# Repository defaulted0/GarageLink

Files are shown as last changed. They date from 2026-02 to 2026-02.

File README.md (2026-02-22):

# GarageLink
**A local, DIY smart garage controller built on the Raspberry Pi Pico 2 W.**

> [!IMPORTANT]
> GarageLink needs an existing HomeAssistant setup to function. You may need additional devices beyond those outlined in the ReadMe.

## Overview

GarageLink is a Home Assistant–integrated garage controller that simulates a wall button press using a relay.  
It connects over WiFi, publishes via MQTT, and adds movement-aware status correction (optional).

It works by momentarily bridging the same two terminals used by the wall button, effectively simulating a button press.

---

## Hardware Requirements

### 1. Raspberry Pi Pico 2 W
- Built-in WiFi
- Controls relays and sensors
- Connects everything

### 2. 5V Relay Module
- Used to simulate a wall button press
- COM and NO terminals only
- Optocoupled boards preferred

### 3. Low-Voltage Wire / Thermostat / Doorbell Wire (18/2 or 22/2 solid copper)
- Pretty cheap on Amazon
- Doorbell, Thermostat, and low-voltage wire are all basically the same.
- Used to connect the relay to the opener terminals
- **Highly** recommended to mount your GarageLink away from the main opener as the WiFi on GarageLink interferes with the RF signal your garage remote uses and your car uses.

### 4. Optional Sensors
- SW-420 vibration sensor
- Used to update the open/close status if an outside entity controls the door. (Wall button, HomeLink, etc.)
- Mark Open and Mark Closed triggers are published to HomeAssistant, too.

## 5. 5V Power Supply
- USB wall adapter works perfectly
- Check if you have a wall outlet near your garage; you probably do. If not, try not to use a battery pack as the voltage is unreliable, and who wants to charge their garage door?

---

## Wiring / Hardware Setup

> [!CAUTION]
> Disconnect the power to your opener before installation.

### Pico → Relay

| Pico Pin | Relay Pin |
|---|---|
| GP17 | IN2 |
| GP16 | IN1 |
| GND | GND |
| VSYS | VCC (5V)  |

>The "IN" pin corresponds to the relay you use on your board.
Adjust GPIO pins as needed in the code.
Use both IN1 and IN2 when wiring two garage doors. If not, use one.
---

### Relay → Garage Opener

For each door:

| Relay Terminal | Opener Terminal |
|---|---|
| COM | Wall terminal |
| NO | Wall terminal |

- Leave NC unused.
- Keep existing wall button wires connected.
- It doesn't matter which order, but which terminals do. Check where your garage's wall buttons connect.
> [!IMPORTANT]
> Check if your wall buttons still work; stuff happens. Better to be safe.

---

### Optional Vibration Sensor

| Sensor Pin | Pico Pin |
|---|---|
| VCC | 3V3 |
| GND | GND |
| DO | GP14 |

Used only for movement detection, not for triggering the relay.

---

## Software Setup

### 1. Install Thonny
https://thonny.org

### 2. Flash MicroPython on Pico
- In the bottom right corner, click the Interpreter, then Configure interpreter.
- At the top, select the Interpreter "MicroPython (RP2040)"
- Click "Install or update MicroPython"
- Choose your Pico as the Target Volume
- MicroPython Family: RP2
- Variant: Raspberry Pi Pico 2 W
- Install

### 3. Upload Files
- Paste in `garage.py`
- Save it to the Pico as `garage.py`
  
- Paste in `main.py`
- Save it to the Pico as `main.py`
> GarageLink will now auto-run on boot.

## Home Assistant Setup

GarageLink uses MQTT discovery.

>[!IMPORTANT]
>Make a new user in HomeAssistant for MQTT. You will use its details for the MQTT config.

Requirements:
- MQTT broker running
- Home Assistant installed
- MQTT integration enabled

Once connected, the following entities should appear:
- `cover.garage_door`
- Availability sensor (if applicable)
- Sync buttons

---

## Configuration

The table is what setting, and then which variable that setting is.

| Setting | Variable |
|---|---|
| WiFi Name | WIFI_SSID = “” |
| Wifi Password | WIFI_PASS = “” | 
| MQTT Host (Usually HomeAssistant IP) | MQTT_BROKER="" |
| MQTT Username | MQTT_USER="" |
| MQTT Password | MQTT_PASS=""

>[!NOTE]
>Make sure all of the necessary fields have been edited in `garage.py`

---
## Status LED

- GarageLink includes support for a recommended status LED.
- Connects to GP12 and GND

- Error Codes and meanings are available in the docs section of this repo.

## Install Install

### 1. Find install area
Decide and find the installation area near your garage opener. **Please** don't just put it on top of the door opener. You'll regret it down the line. Ideal to put it on your ceiling, 2-4 feet away. Further = Better (Kinda)

### 2. Install GarageLink Box
Drill or screw or tape or whatever your GarageLink box into your installation area. If you are too cool to print the one I made, make your own. I don't care. Make sure your wire fits before fully installing it.

### 3. Prepare and strip wires.
Strip your low-voltage wire to length and expose both ends on each side. Connect an optional LED to GPIO 12.

### 4. Connect it up
Connect everything up with the outlined wiring instructions above.

### 5. Done!
Plug in GarageLink and yay! If it doesn't work, check logs, and *please* feel free to create an issue on GitHub.

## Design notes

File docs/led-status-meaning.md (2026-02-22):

# LED Status Reference

GarageLink includes a single status LED to communicate system state without requiring Home Assistant access.

This LED provides live feedback about:

- WiFi connection
- MQTT connection
- Door position state
- Door movement
- Error or unknown states

This document explains exactly what each LED pattern means.

---

## Quick Reference

| LED Pattern | Meaning |
|---|---|
| Solid ON | System healthy, door CLOSED |
| Mostly ON, brief OFF pulse | System healthy, door OPEN |
| Slow blink (0.5s on / 0.5s off) | Door is moving |
| Double blink, pause | Unknown or stopped state |
| OFF | Not connected to MQTT |
| Short flash every ~2s | Reconnecting to MQTT |

---

## Detailed Behavior

### Solid ON

The LED remains continuously ON.

Indicates:
- WiFi connected
- MQTT connected
- System healthy
- Door state is known
- Door is CLOSED

This is the normal idle state.

---

### Mostly ON With Brief OFF Pulse

The LED stays ON but briefly turns OFF every few seconds.

Indicates:
- WiFi connected
- MQTT connected
- Door is OPEN

This subtle pulse acts as a reminder that the garage door is not closed.

---

### Slow Blink (500ms On / 500ms Off)

The LED blinks evenly at a steady rhythm.

Indicates:
- Door is OPENING
- Door is CLOSING

This state occurs:
- After a command is sent
- When movement is detected

---

### Double Blink Pattern

Two quick flashes followed by a pause.

Indicates:
- Door state is UNKNOWN
- Door state is STOPPED
- System recently rebooted
- State synchronization incomplete

This usually resolves once the door state is confirmed.

---

### LED OFF

The LED remains completely OFF.

Indicates:
- Not connected to MQTT
- Broker unreachable
- Network failure
- Device booting but not yet connected

If the LED remains OFF for more than 30 seconds after boot, check:

- WiFi credentials
- MQTT broker IP
- Power supply

---

### Short Flash Every ~2 Seconds

Single short flash at regular intervals.

Indicates:
- Attempting to reconnect to MQTT
- Temporary network interruption

The LED will return to normal state once MQTT reconnects.

---

### Startup Indicators

On boot, the LED provides quick visual confirmation:

- 2 quick flashes → WiFi connected
- 3 quick flashes → MQTT connected

After startup completes, the LED switches to standard operating patterns.

---

### Hardware Wiring

Standard wiring configuration:

- GPIO 12 → 330Ω resistor → LED anode (long leg)
- LED cathode (short leg) → GND

The resistor may be placed on either side of the LED.

---

### Notes

- LED patterns are designed for low visual noise.
- Only one LED is used.
- No RGB or multi-color signaling is implemented.
- System health is primarily reflected by MQTT connectivity.

**Start a discussion or fork if you want to change anything or have any better ideas!**

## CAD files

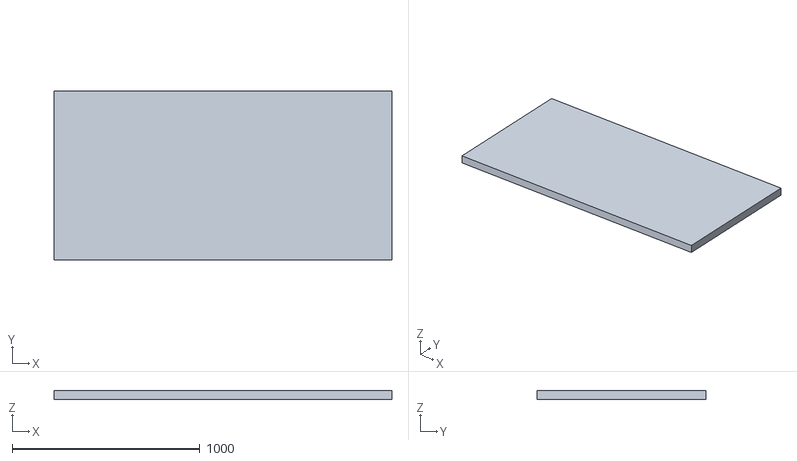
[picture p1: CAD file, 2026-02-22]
case/lid.stl
1800.0 x 900.0 x 50.0

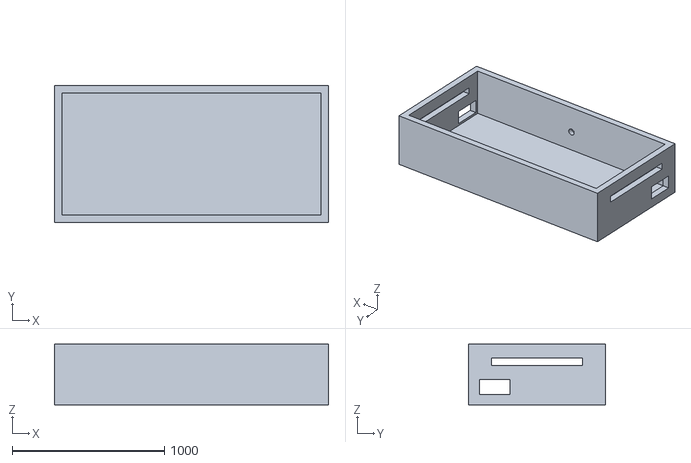
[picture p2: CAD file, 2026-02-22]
case/shell.stl
1800.0 x 900.0 x 400.0

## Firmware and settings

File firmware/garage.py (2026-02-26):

# GarageLink by default
# ------------------------------------------------
print("[BOOT] Pico garage script starting")

import time
import machine    # type: ignore
import network    # type: ignore
import ubinascii  # type: ignore
import ujson      # type: ignore

# MQTT library (make sure /lib/umqtt/simple.py exists on the Pico)
from umqtt.simple import MQTTClient  # type: ignore


# ================================================================                        EDIT HERE!!!!
# USER SETTINGS  (EDIT THESE)                                                         <-------------
# ================================================================
WIFI_SSID = "YOUR_WIFI_NAME"
WIFI_PASS = "YOUR_WIFI_PASSWORD"

MQTT_BROKER = ""     # <--- usually just the ip of your homeassistant host
MQTT_PORT   = 1883
MQTT_USER   = ""
MQTT_PASS   = ""

BASE_TOPIC  = "pico2w/garage1"

# Relay output (your relay IN2 is on GP17)
RELAY_PIN = 17
RELAY_ACTIVE_LOW = True

# Pulse duration (button press length)
PULSE_MS   = 500
LOCKOUT_MS = 3000

# Estimated travel time (used for opening/closing status)
TRAVEL_MS = 14000
IGNORE_WHILE_MOVING = True

# Status LED
LED_PIN = 12
LED_ACTIVE_HIGH = True

# Door position sensor (reed) - OFF by default
USE_DOOR_SENSOR = False
DOOR_PIN = 14
DOOR_OPEN_WHEN_PIN_LOW = True

# Vibration sensor (SW-420) - OFF by default
USE_VIBRATION = False
VIB_PIN = 14
VIB_ACTIVE_HIGH = True
VIB_MIN_MS = 2000                 # must vibrate this long to count as motion
VIB_IGNORE_AFTER_CMD_MS = 3000    # ignore vibration right after relay press
VIB_NO_MOVE_ALERT_MS = 6000       # publish alert if no vibration after command
VIB_END_QUIET_MS = 1500           # how long of quiet to consider motion ended
# ================================================================


# ----------------------------
# Topics
# ----------------------------
CMD_TOPIC    = BASE_TOPIC + "/command"       # HA -> Pico
SYNC_TOPIC   = BASE_TOPIC + "/sync"          # HA -> Pico (mark open/closed)
STATUS_TOPIC = BASE_TOPIC + "/status"        # Pico -> HA (cover state)
STATE_TOPIC  = BASE_TOPIC + "/door_state"    # Pico -> HA (binary sensor if reed enabled)
AVAIL_TOPIC  = BASE_TOPIC + "/availability"  # online/offline
ALERT_TOPIC  = BASE_TOPIC + "/alert"         

DISCOVERY_PREFIX = "homeassistant"


# LED helpers
wifi_ok = False
mqtt_ok = False
led_state = "UNKNOWN"
led_trying = False
_led_last_ms = 0
_led_phase = 0
_led_on = False

def led_init():
    try:
        return machine.Pin(LED_PIN, machine.Pin.OUT)
    except Exception:
        try:
            return machine.Pin(25, machine.Pin.OUT)
        except Exception:
            return None

def led_set(led, on: bool):
    if led is None:
        return
    val = 1 if on else 0
    if not LED_ACTIVE_HIGH:
        val ^= 1
    led.value(val)

def led_blink(led, count=1, on_ms=120, off_ms=120):
    if led is None:
        return
    for _ in range(count):
        led_set(led, True)
        time.sleep_ms(on_ms)
        led_set(led, False)
        time.sleep_ms(off_ms)

def led_tick(led, est_state_now: str):
    global _led_last_ms, _led_phase, _led_on

    if led is None:
        return

    s = (est_state_now or "UNKNOWN").upper()
    now = time.ticks_ms()

    if not mqtt_ok:
        if not led_trying:
            led_set(led, False)
            _led_on = False
            _led_phase = 0
            _led_last_ms = now
            return

        # trying
        if _led_phase == 0:
            led_set(led, True)
            _led_on = True
            _led_phase = 1
            _led_last_ms = now
        else:
            if _led_on and time.ticks_diff(now, _led_last_ms) >= 120:
                led_set(led, False)
                _led_on = False
            if time.ticks_diff(now, _led_last_ms) >= 2000:
                _led_phase = 0
                _led_last_ms = now
        return

    if s == "CLOSED":
        led_set(led, True)
        _led_on = True
        _led_phase = 0
        _led_last_ms = now
        return

    if s == "OPEN":
        if time.ticks_diff(now, _led_last_ms) >= 3000:
            _led_last_ms = now
            _led_phase = 0
        if _led_phase == 0:
            led_set(led, False)
            _led_on = False
            _led_phase = 1
            _led_last_ms = now
        elif _led_phase == 1 and time.ticks_diff(now, _led_last_ms) >= 120:
            led_set(led, True)
            _led_on = True
            _led_phase = 2
        return

    if s in ("OPENING", "CLOSING"):
        if time.ticks_diff(now, _led_last_ms) >= 500:
            _led_last_ms = now
            _led_on = not _led_on
            led_set(led, _led_on)
        return

    # unknown/stopped
    if _led_phase == 0:
        led_set(led, True)
        _led_on = True
        _led_phase = 1
        _led_last_ms = now
    elif _led_phase == 1 and time.ticks_diff(now, _led_last_ms) >= 120:
        led_set(led, False)
        _led_on = False
        _led_phase = 2
        _led_last_ms = now
    elif _led_phase == 2 and time.ticks_diff(now, _led_last_ms) >= 120:
        led_set(led, True)
        _led_on = True
        _led_phase = 3
        _led_last_ms = now
    elif _led_phase == 3 and time.ticks_diff(now, _led_last_ms) >= 120:
        led_set(led, False)
        _led_on = False
        _led_phase = 4
        _led_last_ms = now
    elif _led_phase == 4 and time.ticks_diff(now, _led_last_ms) >= 2640:
        _led_phase = 0
        _led_last_ms = now


# wifi/mqtt
def wifi_connect(led=None):
    global wifi_ok
    wlan = network.WLAN(network.STA_IF)
    wlan.active(True)
    print("[WIFI] Connecting to:", WIFI_SSID)

    try:
        hostname = "garagelink-" + ubinascii.hexlify(machine.unique_id())[-4:].decode()
        wlan.config(dhcp_hostname=hostname)
    except Exception:
        pass

    if wlan.isconnected():
        ip = wlan.ifconfig()[0]
        print("[WIFI] Already connected, IP:", ip)
        wifi_ok = True
        return wlan

    wlan.connect(WIFI_SSID, WIFI_PASS)
    t0 = time.ticks_ms()
    while not wlan.isconnected():
        if time.ticks_diff(time.ticks_ms(), t0) > 20000:
            raise RuntimeError("WiFi connect timeout")
        time.sleep_ms(250)

    ip = wlan.ifconfig()[0]
    print("[WIFI] Connected, IP:", ip)
    wifi_ok = True
    led_blink(led, count=2)
    return wlan

def mqtt_connect(client_id, will_topic, will_msg, led=None):
    global mqtt_ok
    print("[MQTT] Connecting to broker:", MQTT_BROKER)

    cid = client_id if isinstance(client_id, (bytes, bytearray)) else str(client_id).encode()
    usr = MQTT_USER.encode() if MQTT_USER else None
    pwd = MQTT_PASS.encode() if MQTT_PASS else None

    c = MQTTClient(
        client_id=cid,
        server=MQTT_BROKER,
        port=int(MQTT_PORT),
        user=usr,
        password=pwd,
        keepalive=60
    )
    c.set_last_will(will_topic, will_msg, retain=True, qos=0)
    c.connect()

    mqtt_ok = True
    print("[MQTT] Connected")
    led_blink(led, count=3)
    return c


# Home Assistant Discovery (MQTT)
def publish_discovery(client, unique, device_name):
    # Cover entity
    cover_id = unique + "_cover"
    cover_cfg_topic = f"{DISCOVERY_PREFIX}/cover/{cover_id}/config"
    cover_cfg = {
        "name": "GarageLink",   # just rename in homeassistant
        "unique_id": cover_id,
        "command_topic": CMD_TOPIC,
        "state_topic": STATUS_TOPIC,
        "availability_topic": AVAIL_TOPIC,
        "payload_available": "online",
        "payload_not_available": "offline",
        "payload_open": "OPEN",
        "payload_close": "CLOSE",
        "payload_stop": "STOP",
        "state_open": "OPEN",
        "state_opening": "OPENING",
        "state_closed": "CLOSED",
        "state_closing": "CLOSING",
        "state_stopped": "STOPPED",
        "device": {
            "identifiers": [unique],
            "name": device_name,
            "manufacturer": "Raspberry Pi",
            "model": "Pico 2 W",
        }
    }
    client.publish(cover_cfg_topic, ujson.dumps(cover_cfg), retain=True)
    print("[MQTT] Discovery cover published")

    # Door binary sensor (reed)
    if USE_DOOR_SENSOR:
        sensor_id = unique + "_door"
        sensor_cfg_topic = f"{DISCOVERY_PREFIX}/binary_sensor/{sensor_id}/config"
        sensor_cfg = {
            "name": "Garage Door Open",
            "unique_id": sensor_id,
            "state_topic": STATE_TOPIC,
            "payload_on": "OPEN",
            "payload_off": "CLOSED",
            "device_class": "garage_door",
            "availability_topic": AVAIL_TOPIC,
            "payload_available": "online",
            "payload_not_available": "offline",
            "device": {
                "identifiers": [unique],
                "name": device_name,
                "manufacturer": "Raspberry Pi",
                "model": "Pico 2 W",
            }
        }
        client.publish(sensor_cfg_topic, ujson.dumps(sensor_cfg), retain=True)
        print("[MQTT] Discovery door sensor published")

    # Sync buttons
    sync_open_id = unique + "_sync_open"
    sync_open_cfg_topic = f"{DISCOVERY_PREFIX}/button/{sync_open_id}/config"
    sync_open_cfg = {
        "name": "Garage: Mark Open",
        "unique_id": sync_open_id,
        "command_topic": SYNC_TOPIC,
        "payload_press": "OPEN",
        "availability_topic": AVAIL_TOPIC,
        "payload_available": "online",
        "payload_not_available": "offline",
        "icon": "mdi:garage-open",
        "device": {
            "identifiers": [unique],
            "name": device_name,
            "manufacturer": "Raspberry Pi",
            "model": "Pico 2 W",
        }
    }
    client.publish(sync_open_cfg_topic, ujson.dumps(sync_open_cfg), retain=True)

    sync_closed_id = unique + "_sync_closed"
    sync_closed_cfg_topic = f"{DISCOVERY_PREFIX}/button/{sync_closed_id}/config"
    sync_closed_cfg = {
        "name": "Garage: Mark Closed",
        "unique_id": sync_closed_id,
        "command_topic": SYNC_TOPIC,
        "payload_press": "CLOSED",
        "availability_topic": AVAIL_TOPIC,
        "payload_available": "online",
        "payload_not_available": "offline",
        "icon": "mdi:garage",
        "device": {
            "identifiers": [unique],
            "name": device_name,
            "manufacturer": "Raspberry Pi",
            "model": "Pico 2 W",
        }
    }
    client.publish(sync_closed_cfg_topic, ujson.dumps(sync_closed_cfg), retain=True)
    print("[MQTT] Discovery sync buttons published")
# Relay control
def make_relay(pin_num):
    pin = machine.Pin(pin_num, machine.Pin.IN)  # Hi-Z idle
    print("[RELAY] Idle set to Hi-Z (Pin.IN) on GP", pin_num)
    return pin

def relay_pulse(relay_pin, led=None):
    print("[RELAY] Pulse triggered")
    # optional quick blink to show activity
    led_blink(led, count=2, on_ms=120, off_ms=120)

    if RELAY_ACTIVE_LOW:
        relay_pin.init(machine.Pin.OUT)
        relay_pin.value(0)
        time.sleep_ms(PULSE_MS)
        relay_pin.init(machine.Pin.IN)
    else:
        relay_pin.init(machine.Pin.OUT)
        relay_pin.value(1)
        time.sleep_ms(PULSE_MS)
        relay_pin.init(machine.Pin.IN)

    print("[RELAY] Returned to Hi-Z (Pin.IN)")

# Door sensor (reed) helper
def read_door_state(door_pin):
    v = door_pin.value()
    is_open = (v == 0) if DOOR_OPEN_WHEN_PIN_LOW else (v == 1)
    return "OPEN" if is_open else "CLOSED"

# Vibration helper
def vib_active(vpin):
    v = vpin.value()
    return (v == 1) if VIB_ACTIVE_HIGH else (v == 0)


# ----------------------------
# Main
# ----------------------------
unique = ubinascii.hexlify(machine.unique_id()).decode()
device_name = "GarageLink Controller"

led = led_init()
led_set(led, False)
print("[LED] Status LED init:", bool(led))

relay = make_relay(RELAY_PIN)
print("[RELAY] Initialized on GP", RELAY_PIN, "active_low =", RELAY_ACTIVE_LOW)

door_pin = None
last_door = None
if USE_DOOR_SENSOR:
    door_pin = machine.Pin(DOOR_PIN, machine.Pin.IN, machine.Pin.PULL_UP)
    last_door = read_door_state(door_pin)
    print("[DOOR] Initial:", last_door)

vpin = None
if USE_VIBRATION:
    vpin = machine.Pin(VIB_PIN, machine.Pin.IN)
    print("[VIB] Enabled on GP", VIB_PIN)

# State machine
est_state = "UNKNOWN"  # UNKNOWN/OPENING/CLOSING/OPEN/CLOSED/STOPPED Must open or close first to set state on boot!
move_end_ms = None
last_press_ms = 0

# Vibration logic state
_cmd_ms = None
_expect_motion = False
_vib_start_ms = None
_last_vib_ms = None
_motion_confirmed = False


def publish_status(client, state, retain=True):
    global est_state
    est_state = state
    try:
        client.publish(STATUS_TOPIC, state, retain=retain)
        print("[STATUS] ->", state)
    except Exception as e:
        print("[STATUS] publish failed:", e)

def publish_alert(client, text):
    try:
        client.publish(ALERT_TOPIC, text, retain=False)
        print("[ALERT] ->", text)
    except Exception as e:
        print("[ALERT] publish failed:", e)


def on_mqtt_msg(topic, msg):
    global last_press_ms, est_state, move_end_ms
    global _cmd_ms, _expect_motion, _motion_confirmed

    t = topic.decode() if isinstance(topic, (bytes, bytearray)) else str(topic)
    m = msg.decode().strip().upper()
    now = time.ticks_ms()
    print("[MQTT] RX:", t, m)

    # Sync buttons: correct state without moving
    if t == SYNC_TOPIC:
        if m in ("OPEN", "CLOSED", "UNKNOWN", "STOPPED"):
            move_end_ms = None
            publish_status(client, m, retain=True)
        return

    if t != CMD_TOPIC:
        return

    if m not in ("OPEN", "CLOSE", "STOP", "TRIGGER", "TOGGLE", "PRESS", "ON", "1"):
        return

    # Lockout
    if time.ticks_diff(now, last_press_ms) < LOCKOUT_MS:
        print("[RELAY] Ignored (lockout)")
        return

    # STOP: only meaningful while moving
    if m == "STOP":
        if est_state in ("OPENING", "CLOSING"):
            last_press_ms = now
            relay_pulse(relay, led=led)
            publish_status(client, "STOPPED", retain=True)
        return

    # Ignore while moving (optional)
    if IGNORE_WHILE_MOVING and est_state in ("OPENING", "CLOSING"):
        print("[STATE] Ignored (already moving):", est_state)
        return

    # Trigger relay
    last_press_ms = now
    relay_pulse(relay, led=led)

    # Mark that we "expect" motion soon (for vibration alert logic)
    _cmd_ms = now
    _expect_motion = True
    _motion_confirmed = False

    # Update estimated movement state
    if m == "OPEN":
        publish_status(client, "OPENING", retain=True)
    elif m == "CLOSE":
        publish_status(client, "CLOSING", retain=True)
    else:
        # toggle
        if est_state in ("CLOSED", "CLOSING", "UNKNOWN", "STOPPED"):
            publish_status(client, "OPENING", retain=True)
        else:
            publish_status(client, "CLOSING", retain=True)

    move_end_ms = time.ticks_add(now, TRAVEL_MS)


def safe_sleep_ms(ms):
    step = 50
    remaining = ms
    while remaining > 0:
        time.sleep_ms(step if remaining > step else remaining)
        remaining -= step


# Connect WiFi + MQTT
wifi_connect(led)

client_id = b"garagelink-" + ubinascii.hexlify(machine.unique_id())
client = mqtt_connect(client_id, AVAIL_TOPIC, b"offline", led=led)

client.set_callback(on_mqtt_msg)

client.subscribe(CMD_TOPIC.encode())
client.subscribe(SYNC_TOPIC.encode())
print("[MQTT] Subscribed:", CMD_TOPIC, "and", SYNC_TOPIC)

client.publish(AVAIL_TOPIC, b"online", retain=True)
print("[MQTT] Availability online")

publish_discovery(client, unique, device_name)

# Publish initial states
if USE_DOOR_SENSOR and last_door is not None:
    client.publish(STATE_TOPIC, last_door, retain=True)
    publish_status(client, last_door, retain=True)
else:
    publish_status(client, est_state, retain=True)


# Main loop
while True:
    try:
        client.check_msg()

        # LED tick
        led_tick(led, est_state)

        now = time.ticks_ms()

        # If no door sensor, timer completes OPENING/CLOSING into OPEN/CLOSED
        if (not USE_DOOR_SENSOR) and move_end_ms is not None and time.ticks_diff(now, move_end_ms) >= 0:
            if est_state == "OPENING":
                publish_status(client, "OPEN", retain=True)
            elif est_state == "CLOSING":
                publish_status(client, "CLOSED", retain=True)
            move_end_ms = None

        # Door sensor overrides estimate (true open/closed)
        if USE_DOOR_SENSOR and door_pin is not None:
            current = read_door_state(door_pin)
            if current != last_door:
                last_door = current
                print("[DOOR] Changed:", current)
                client.publish(STATE_TOPIC, current, retain=True)
                move_end_ms = None
                publish_status(client, current, retain=True)

        # Vibration-based movement detection (state correction only)
        if USE_VIBRATION and vpin is not None:
            active = vib_active(vpin)

            if active:
                if _vib_start_ms is None:
                    _vib_start_ms = now
                _last_vib_ms = now

                # Confirm sustained motion
                if time.ticks_diff(now, _vib_start_ms) >= VIB_MIN_MS:
                    _motion_confirmed = True
            else:
                _vib_start_ms = None

            # Ignore vibration shortly after command (relay click / motor startup noise)
            if _cmd_ms is not None and time.ticks_diff(now, _cmd_ms) < VIB_IGNORE_AFTER_CMD_MS:
                pass
            else:
                # If motion confirmed, flip direction based on current state (your rule)
                if _motion_confirmed:
                    if est_state in ("CLOSED", "CLOSING", "UNKNOWN", "STOPPED"):
                        publish_status(client, "OPENING", retain=True)
                    else:
                        publish_status(client, "CLOSING", retain=True)
                    _motion_confirmed = False

            # Motion ended (quiet for a while) -> finalize opposite (estimated)
            if _last_vib_ms is not None and time.ticks_diff(now, _last_vib_ms) > VIB_END_QUIET_MS:
                if est_state == "OPENING":
                    publish_status(client, "OPEN", retain=True)
                elif est_state == "CLOSING":
                    publish_status(client, "CLOSED", retain=True)

                _last_vib_ms = None
                _expect_motion = False

            # If we commanded movement but saw no vibration in time -> alert
            if _expect_motion and _cmd_ms is not None and time.ticks_diff(now, _cmd_ms) > VIB_NO_MOVE_ALERT_MS:
                publish_alert(client, "Command sent but no vibration detected. Door may not have moved.")
                _expect_motion = False

        safe_sleep_ms(100)

    except OSError:
        print("[ERROR] MQTT/WiFi error, reconnecting...")
        mqtt_ok = False
        led_trying = True
        led_tick(led, est_state)

        try:
            client.publish(AVAIL_TOPIC, b"offline", retain=True)
        except Exception:
            pass

        # Reconnect WiFi if needed
        try:
            wlan = network.WLAN(network.STA_IF)
            if not wlan.isconnected():
                wifi_connect(led)
        except Exception:
            pass

        # Reconnect MQTT loop
        while True:
            try:
                client = mqtt_connect(client_id, AVAIL_TOPIC, b"offline", led=led)
                led_trying = False
                mqtt_ok = True

                client.set_callback(on_mqtt_msg)
                client.subscribe(CMD_TOPIC.encode())
                client.subscribe(SYNC_TOPIC.encode())

                client.publish(AVAIL_TOPIC, b"online", retain=True)
                publish_discovery(client, unique, device_name)

                if USE_DOOR_SENSOR and last_door is not None:
                    client.publish(STATE_TOPIC, last_door, retain=True)

                publish_status(client, est_state, retain=True)
                break
            except Exception:
                time.sleep(2)

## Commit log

2026-02-22 stl file case thing
    [garagebox2.0.stl]
2026-02-22 lid for case
    [garagelinklid.stl]
2026-02-22 fix led error
